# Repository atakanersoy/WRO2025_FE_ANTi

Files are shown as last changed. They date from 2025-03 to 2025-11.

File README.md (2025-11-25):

# 🚀 WRO 2025 Future Engineers – ANTi

<center>
Banner



</center>

---

## 🏆 **TURKISH NATIONAL CHAMPION – READY FOR SINGAPORE FINALS**

Welcome to the GitHub repository of **Team ANTi**, competing in the **World Robot Olympiad™ (WRO®) Future Engineers 2025** category. Our team is made up of Turkish students who have designed a compact, innovative, and autonomous self-driving vehicle to tackle the dynamic challenges of the WRO 2025 competition. Our team name, **ANTi**, reflects our philosophy: like an **ANT**, our robot is exceptionally small yet highly capable, pushing the boundaries of minimalism in design. The "**ANT**i" signifies our competitive spirit, standing "versus the world" in pursuit of engineering excellence.

Our mission was to create the smallest possible robot for the WRO 2025 challenge, leveraging our expertise in electrical, mechanical, and software engineering to test the limits of the 3 m x 3 m game field. After winning the Turkish National Final, we rebuilt, re-tuned, and re-documented every subsystem for the International Final in Singapore on 26–28 Nov 2025.
Current best times on the 3 m x 3 m field:
- **Open Challenge**: 16 seconds (full score)
- **Obstacle Challenge**: 35 seconds (full score)

Complete performance demonstrations available in our [video documentation](video/README.md).

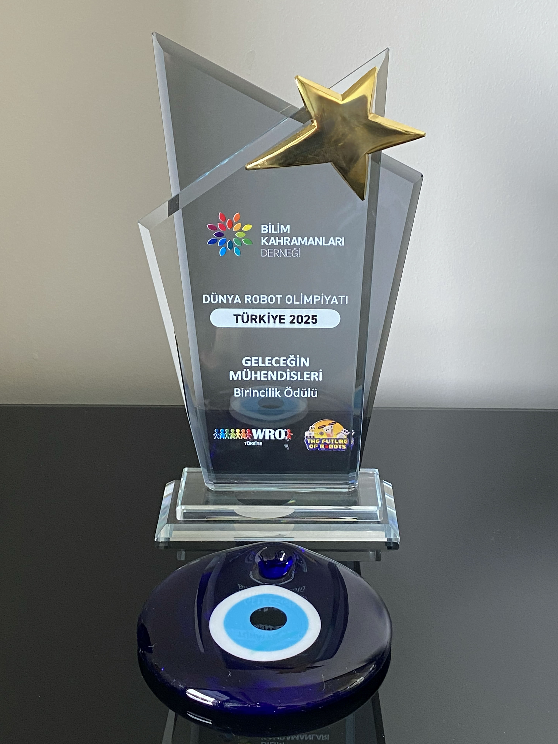
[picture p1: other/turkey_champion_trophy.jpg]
Turkey National Champion Trophy
 

The car keeps its title of **World's Smallest Self Driving Autonomous Vehicle** (about 1/76 scale, **69mm (L) x 53mm (W) x 57mm (H)**) while now carrying more intelligence and sensors than ever before. We challenged ourselves beyond the traditional competition rules by pursuing minimal size alongside advanced engineering functionality to further develop our **engineering knowledge**.

Guided by our vision to ***"never stop developing unless we stop learning,"*** we have created a vehicle that demonstrates how constraints can drive creativity and technical excellence in autonomous systems design. This documentation was last updated on **Sunday, Nov 09 2025, at 09:24 PM +03**

---

## 📚 **Table of Contents**
- [📂 Complete Documentation Structure](#complete-documentation-structure)
- [👥 The Team](#the-team)
- [🎯 Challenge Overview](#challenge-overview)
- [🤖 Our Robot](#our-robot)
- [🔧 Electronic Systems](#electronic-systems)
- [⚙ Mechanical Systems](#mechanical-systems)
- [💻 Software Architecture](#software-architecture)
- [📹 Performance Videos](#performance-videos)
- [🌐 GitHub Utilization & Development](#github-utilization--development)
- [📜 License & Replication](#license--replication)

---

## 📂 **Complete Documentation Structure** 

<div align="center">

## 🔍 **DETAILED TECHNICAL DOCUMENTATION AVAILABLE**

### **Each folder contains comprehensive README documentation with specialized technical content**

| 📁 Folder | 🎯 Technical Content | 📖 Detailed Documentation |
|---|---|---|
| **🧮 MATLAB** | **Vision System Calibration**<br>• LAB colorspace analysis<br>• Threshold optimization<br>• Lighting condition testing | [🔗 Explore MATLAB Documentation](matlab/README.md) |
| **⚙ Models** | **Mechanical Engineering**<br>• 3D CAD designs<br>• Assembly instructions<br>• Gear system calculations | [🔗 Explore 3D Models & Assembly Documentation](models/README.md) |
| **🔌 Schemes** | **Electrical Systems**<br>• Wiring diagrams<br>• Power management<br>• Component schematics & datasheets | [🔗 Explore Schematics & Wiring Documentation](schemes/README.md) |
| **💾 Source Code** | **Software Algorithms**<br>• Navigation logic<br>• Sensor fusion<br>• Control systems | [🔗 Explore Software & Algorithms Documentation](src/README.md) |
| **👥 Team Photos** | **Team Documentation**<br>• Member profiles<br>• Development journey<br>• Competition preparation | [🔗 Explore Team Photos Documentation](t-photos/README.md) |
| **🚗 Vehicle Photos** | **Vehicle Documentation**<br>• Multi-angle views<br>• Component labeling<br>• System integration | [🔗 Explore Vehicle Photos Documentation](v-photos/README.md) |
| **🎥 Videos** | **Performance Validation**<br>• Challenge demonstrations<br>• Engineering tests<br>• System validation | [🔗 Explore Performance Videos Documentation](video/README.md) |
| **📚 Other Resources** | **Technical References**<br>• Component images<br>• Development resources<br>• Additional documentation | [🔗 Explore Additional Resources Documentation](other/README.md) |

</div>

---

## 👥 **The Team** 

Team ANTi includes passionate students from Türkiye, guided by a coach. This is our **first year** competing in the WRO Future Engineers category, and each member brings unique skills to the project, from electronics to computer vision.

<div align="center">
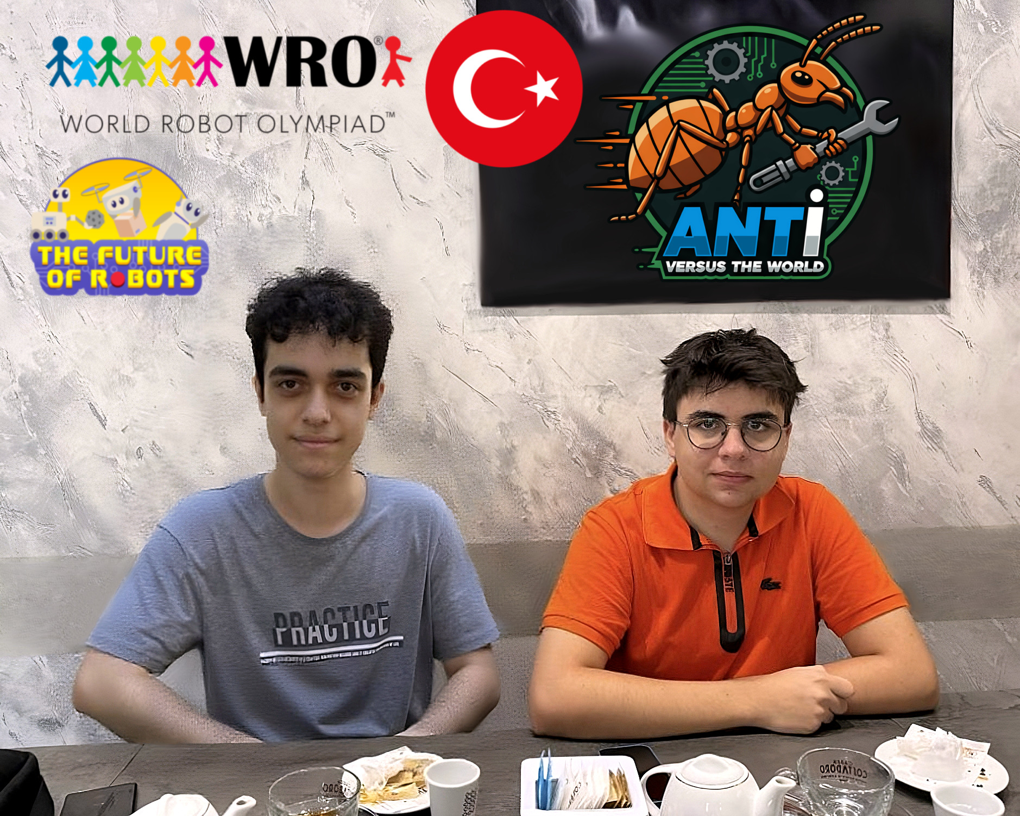
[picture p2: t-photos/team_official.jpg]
Official Team Moment

Team ANTi at Work
</div>

### **Members**
- **Atakan Ersoy** (Team Leader)  
  *Role*: Electronics, Mechanical Design, Software, Strategy Integration  
  *Background*: Sophomore, Electrical and Electronics Engineering, Koç University (2025)  
  *Contact*: [atakan@atakanersoy.com](mailto:atakan@atakanersoy.com), [aersoy24@ku.edu.tr](mailto:aersoy24@ku.edu.tr)  
  *Born*: 2006, Türkiye

- **Ege Özokan**  
  *Role*: Computer Vision Research, Strategy  
  *Background*: Freshman, Computer Engineering, Politecnico di Torino (2025)  
  *Born*: 2006, Türkiye

### **Coach**
- **Ali Aral Eren**  
  *Role*: Team Coach, Connector  
  *Background*: Alumni, Electrical and Electronics Engineering, Koç University (2025)  
  *Born*: 2003, Türkiye  
<br>
<div align="center">
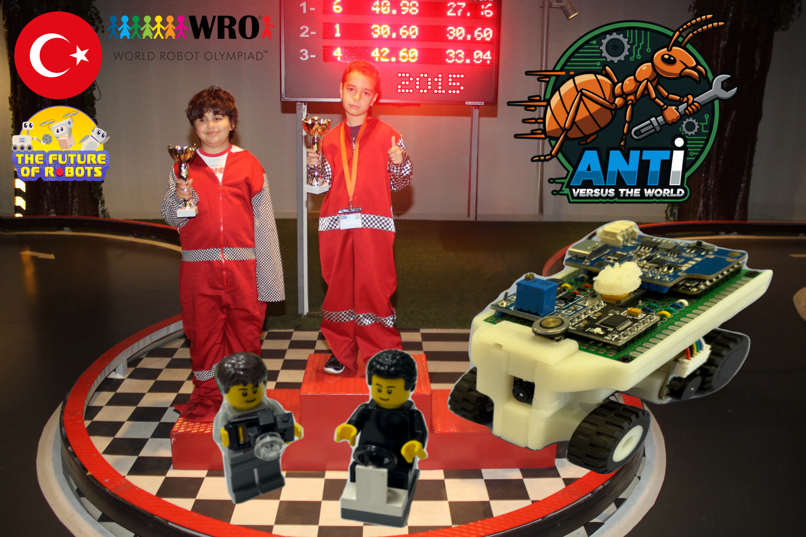
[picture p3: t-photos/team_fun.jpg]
Team ANTi Fun Photo

</div>

> 💡 *Fun Fact*: The fun team photo (`team_fun.jpg`) is our childhood photo from 2015, when we were 9 years old, standing on a go-kart race podium!

### **Team Journey Moments**
Throughout our development process from initial concept to competition readiness, we captured key moments demonstrating our collaborative spirit and technical dedication. These images showcase our brainstorming sessions, technical adjustments, and competition preparation.
<div align="center">
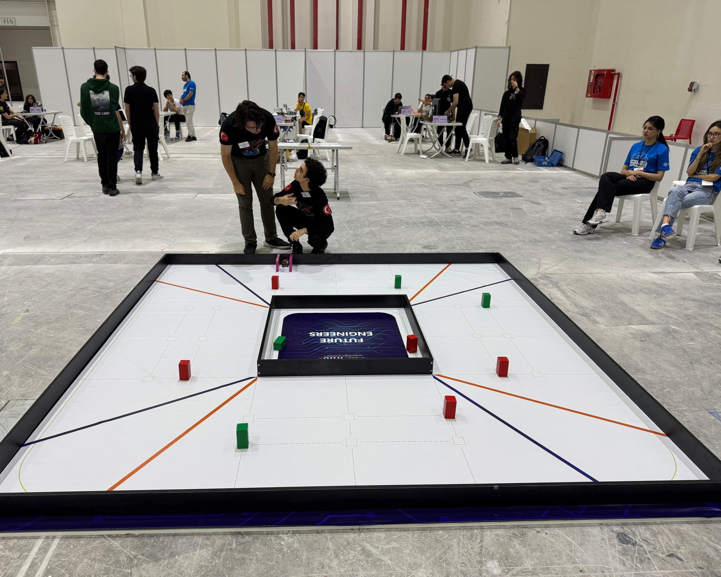
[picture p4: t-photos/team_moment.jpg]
Team Collaboration During National Final

<p><em>Team members collaborating during national final competition - discussing strategy while testing the vehicle on the field and preparing to activate it.</em></p>
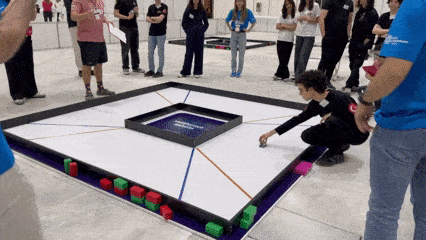
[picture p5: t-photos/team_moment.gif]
Official Competition Start with Team Excitement

<p><em>Dynamic view of official competition start during national final - team member pressing start button with excitement as vehicle begins its run.</em></p>
</div>

---

## 🎯 **Challenge Overview** 

<div align="center">

## 🏁 **WRO 2025 Future Engineers Challenges**

### **Two distinct autonomous navigation challenges testing vehicle intelligence and precision**

</div>

### **🚀 Open Challenge**
<div align="center">

**Objective**: Complete three autonomous laps on dynamically configured tracks

| Aspect | Challenge | Our Solution |
|---|---|---|
| **Track Variability** | Random internal wall placements | Adaptive path planning algorithms |
| **Navigation** | Unknown track layouts each round | Robust wall-following with corner detection |
| **Performance** | Consistent lap times across variations | Optimized PID control and sensor fusion |
| **Precision** | Maintain course in narrow lanes | High-accuracy steering and speed control |

</div>

### **🚧 Obstacle Challenge**
<div align="center">

**Objective**: Navigate three laps with traffic sign compliance and precision parking

| Challenge Element | Requirement | Our Implementation |
|---|---|---|
| **Traffic Signs** | Red → Right bias<br>Green → Left bias | Real-time color detection with LAB colorspace |
| **Obstacle Avoidance** | Dynamic path adjustment | Smooth following at consistent distances |
| **Parking Maneuver** | Parallel parking after lap completion | Multi-stage parking with sensor validation |
| **Navigation** | Shortest path optimization | Efficient routing around obstacle combinations |
</div>

### **📁 Documentation Evaluation Framework**

<div align="center">

## 📊 **WRO 2025 Engineering Documentation Scoring (30 points total)**

| Scoring Area | Maximum Points | Our Documentation Coverage |
|---|---|---|
| **1. Mobility Management** | 4 points | Complete mechanical design, motor selection, steering system, assembly instructions |
| **2. Power & Sense Management** | 4 points | Power systems, sensor integration, wiring diagrams, component specifications |
| **3. Obstacle Management** | 4 points | Navigation algorithms, parking strategies, source code with detailed comments |
| **4. Pictures – Team and Vehicle** | 4 points | Multi-angle vehicle photos, team photos, component labeling |
| **5. Performance Videos** | 4 points | Complete challenge demonstrations with commentary and analysis |
| **6. GitHub Utilization** | 4 points | Version control, structured documentation, regular commits |
| **7. Engineering Factor** | 4 points | Custom design and manufacturing throughout the vehicle |
| **8. Overall Judge Impression** | 2 points | Clear communication enabling easy replication |
| **Total Documentation Score** | **30 points** | **(≈25% of total competition score)** |
</div>

### **Key Evaluation Areas**
- **Performance and adaptability** in randomized track conditions
- **Precision in maneuvers**, especially parallel parking execution  
- **Comprehensive public engineering documentation** on GitHub with complete transparency
- **Custom design innovation** and manufacturing process documentation
- **Professional presentation** enabling effortless replication by other teams

**Scoring Philosophy**: Documentation is evaluated based on completeness, structure, and ease of replication - not comparison between teams. Each scoring area uses a 0-4 point scale where "Exceeds Expectations" requires not only enabling exact duplication but also providing improvement suggestions.

### **🎓 Educational Objectives**
- **Advanced Computer Vision**: Real-world implementation of color space theory
- **Sensor Fusion**: Integrating multiple data sources for robust navigation
- **Control Systems**: Precision steering and speed control algorithms
- **Engineering Documentation**: Professional technical communication
- **Problem Solving**: Systematic approach to technical challenges

---

## 🤖 **Our Robot** 

<div align="center">
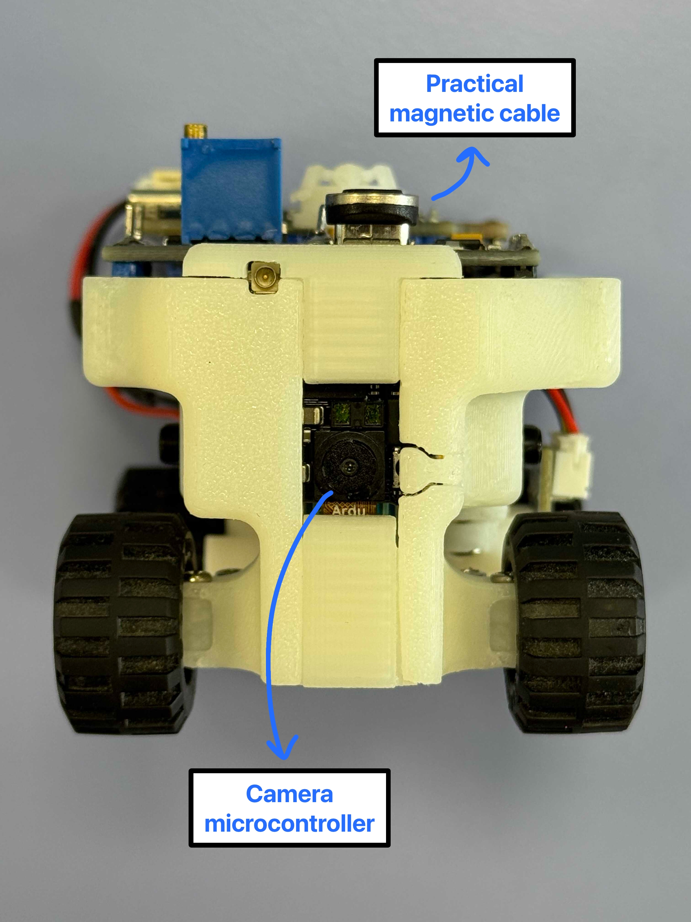
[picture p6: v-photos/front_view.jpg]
ANTi Autonomous Vehicle

</div>

Our platform represents a breakthrough in compact autonomous vehicle design, achieving unprecedented miniaturization without compromising capability. The complete system integrates custom mechanical design with sophisticated electronic systems and advanced software algorithms.

**Core Processing Architecture**:
- **Primary Vision Processor**: STM32H747 dual-core microcontroller dedicated to real-time image processing
- **Secondary Sensor Processor**: nRF52832 microcontroller handling multi-sensor data fusion
- **Distributed Processing**: Optimized task allocation between vision and control subsystems

**Perception System**:
- **Front-Facing Detection**: VL53L1X Time-of-Flight sensor for general obstacle awareness
- **Side-Mounted Precision Sensors**: Dual VL53L3CX ToF sensors with custom optics for parking detection
- **Visual Navigation**: GC2145 2MP camera with optimized field of view for track following

**Propulsion and Control**:
- **Drive System**: 1500 RPM N20 motor with integrated encoder feedback
- **Steering Mechanism**: Custom Ackermann geometry with submicro servo actuation
- **Power Management**: Integrated LiPo system with comprehensive power distribution

Complete vehicle documentation with detailed component identification available in [vehicle photos](v-photos/README.md).

<div align="center">
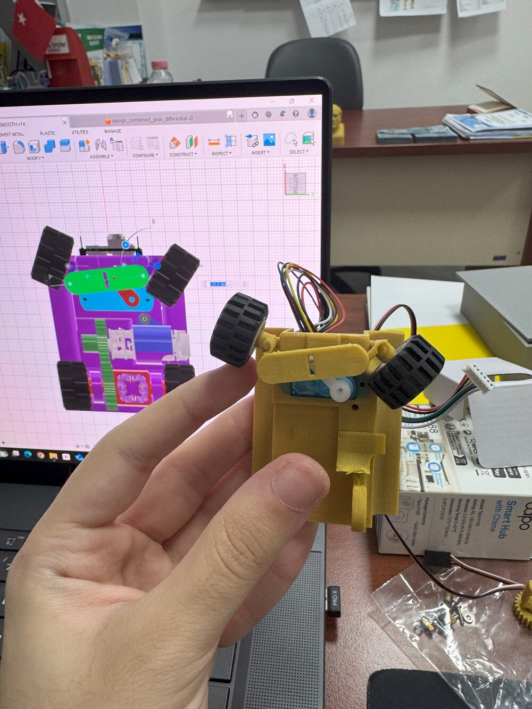
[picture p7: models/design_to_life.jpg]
Digital to Physical Realization

</div>

### Potential Future Improvements (Overall Vehicle)
- Reduce size even further to ≈ 60 × 45 × 50 mm by switching to smaller LiPo (3.7 V), a coreless motor + micro gearbox and smaller mechanic differential style.
- Implement four-wheel steering or active rear-axle 4 wheel drive to control for tighter turning radius on narrow lanes.
- Add a very small extra second camera facing backwards for reverse parking or emergency obstacle detection.

---

## 🔧 **Electronic Systems** 

Our electronic architecture emphasizes modularity, reliability, and hands-on engineering through custom manufacturing approaches.

### **Component Integration Strategy**

<div align="center">

| Component | Image | Quantity | Function | Key Specifications |
|---|---|---|---|---|
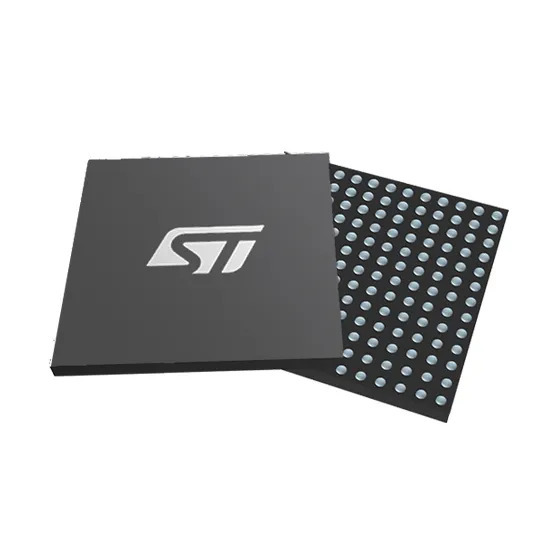
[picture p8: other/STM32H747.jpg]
| **STM32H747** |  | 1 | Vision Processing | Dual-core Cortex-M7/M4, Camera Interface |
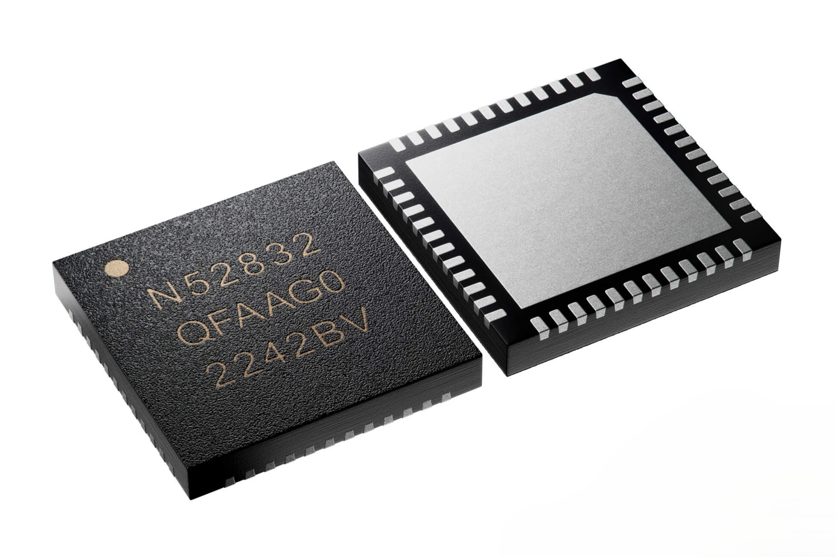
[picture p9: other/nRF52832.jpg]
| **nRF52832** |  | 1 | Sensor Fusion | Multi-protocol wireless capable MCU |
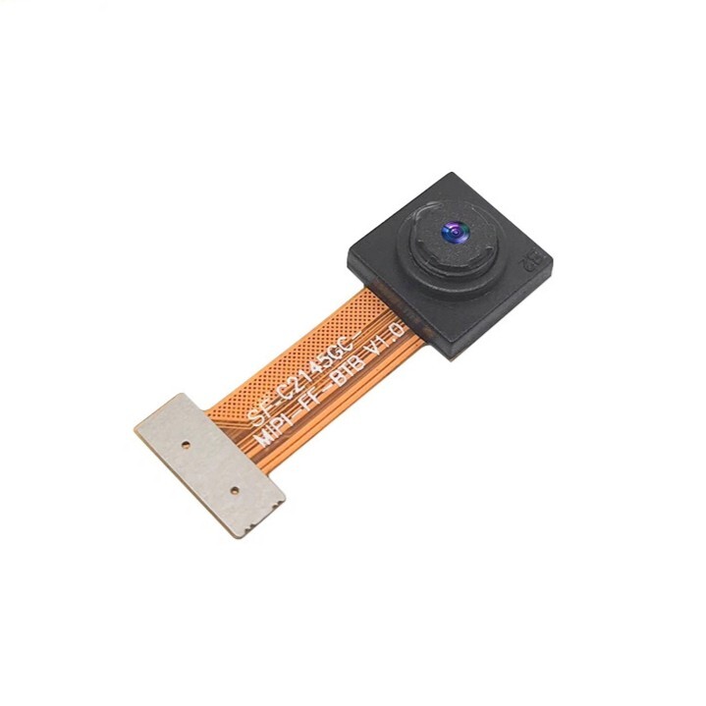
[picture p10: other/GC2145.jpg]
| **GC2145 Camera** |  | 1 | Visual Navigation | 2MP resolution, 80° FOV, DCMI interface |
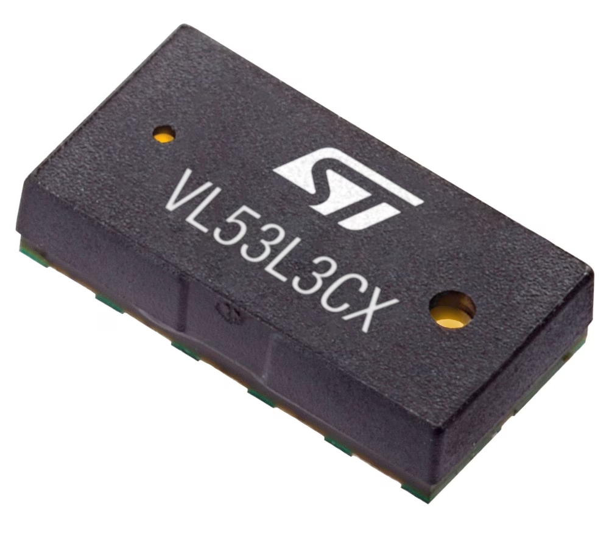
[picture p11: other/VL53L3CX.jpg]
| **VL53L3CX ToF** |  | 2 | Side Detection | 700cm range, window lens optics |
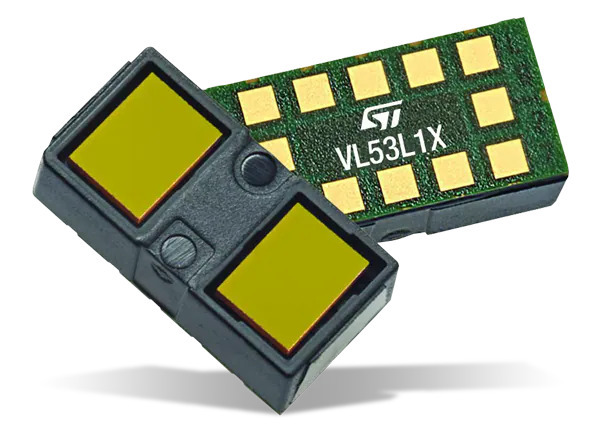
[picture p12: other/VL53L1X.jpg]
| **VL53L1X ToF** |  | 1 | Front Detection | 400cm range, programmable FoV |
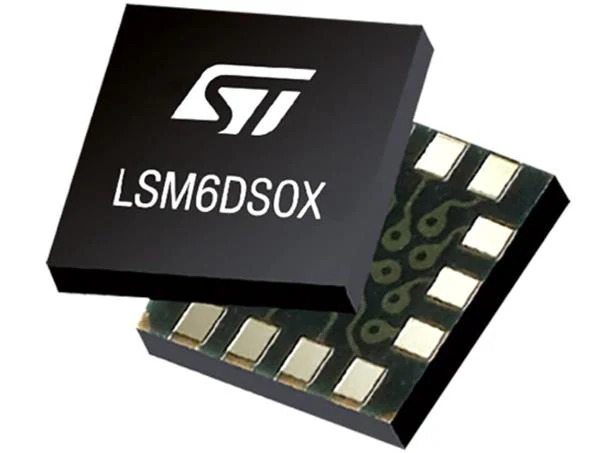
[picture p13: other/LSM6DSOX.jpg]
| **LSM6DSOX IMU** |  | 1 | Motion Tracking | 6-axis inertial measurement |
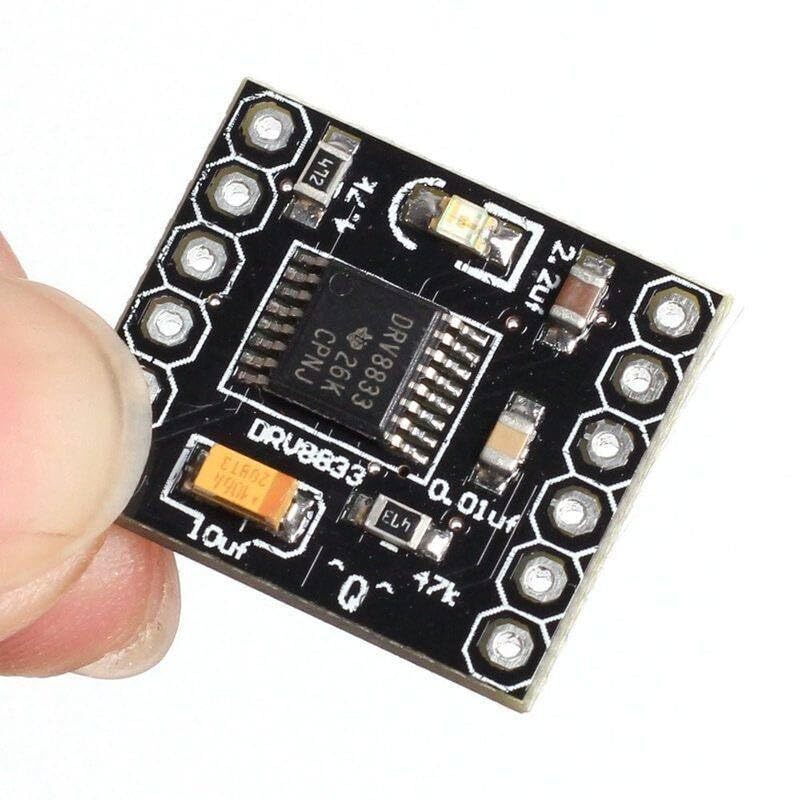
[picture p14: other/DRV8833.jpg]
| **DRV8833 Driver** |  | 1 | Motor Control | Dual H-bridge, PWM control |
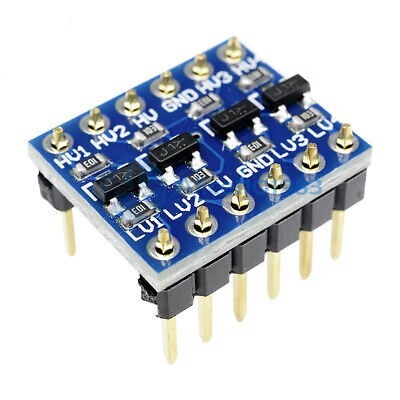
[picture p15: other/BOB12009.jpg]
| **BOB-12009** |  | 1 | Level Shifting | Bidirectional 3.3V-5V conversion |
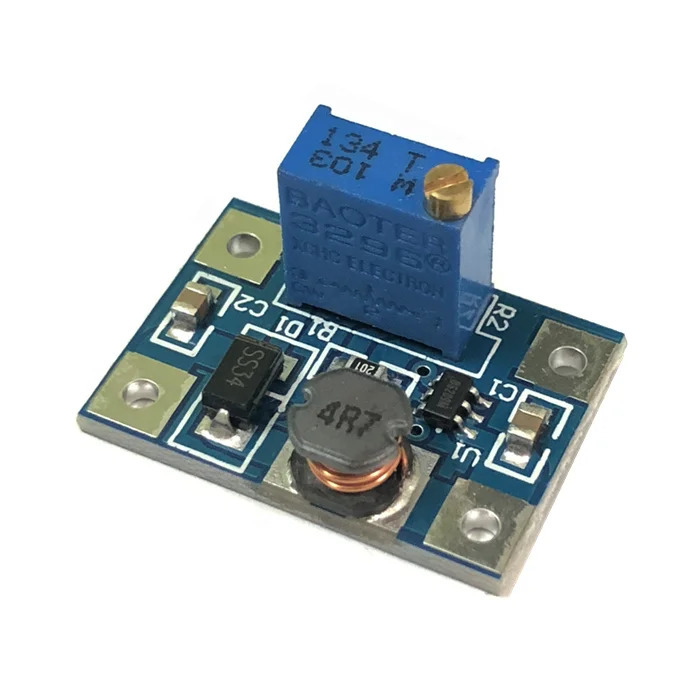
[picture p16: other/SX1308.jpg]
| **SX1308 Booster** |  | 1 | Power Regulation | 2A step-up voltage conversion |
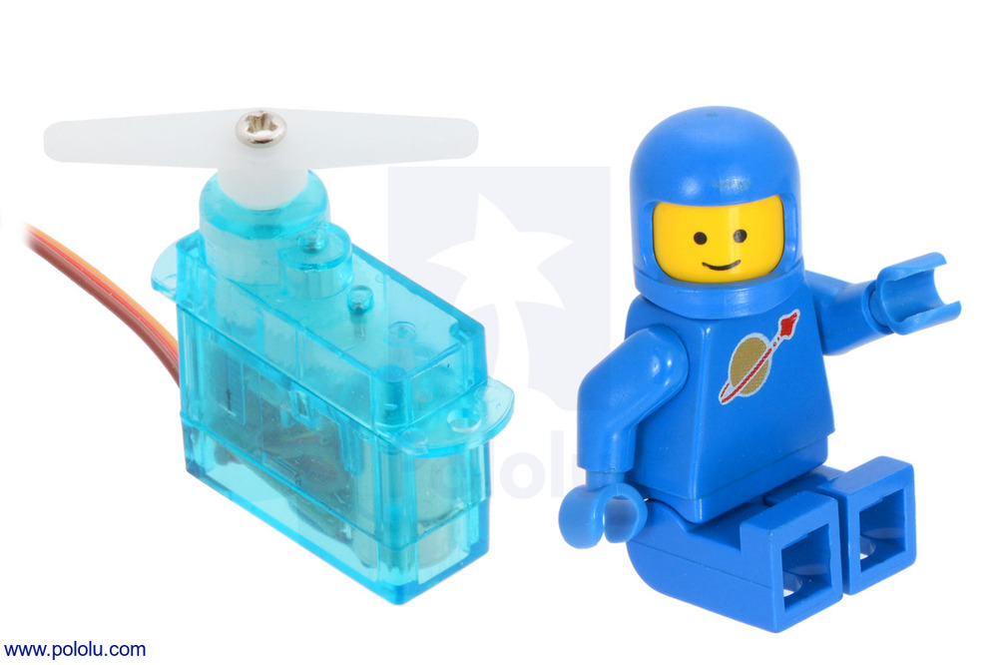
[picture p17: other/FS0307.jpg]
| **Feetech FS0307** |  | 1 | Steering Actuation | Submicro form factor, precision control |
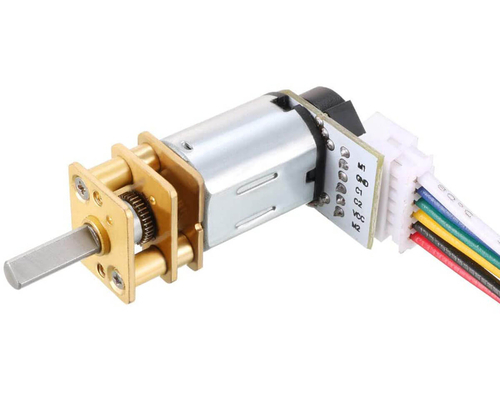
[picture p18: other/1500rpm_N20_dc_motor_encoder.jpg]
| **1500 RPM N20** |  | 1 | Propulsion | Brushed DC with Hall effect encoder |
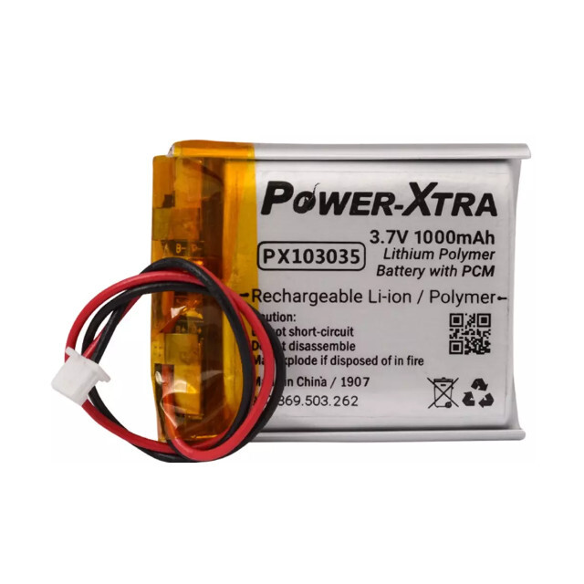
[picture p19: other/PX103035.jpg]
| **PX103035 Battery** |  | 1 | Power Source | 1000mAh LiPo with protection circuit |
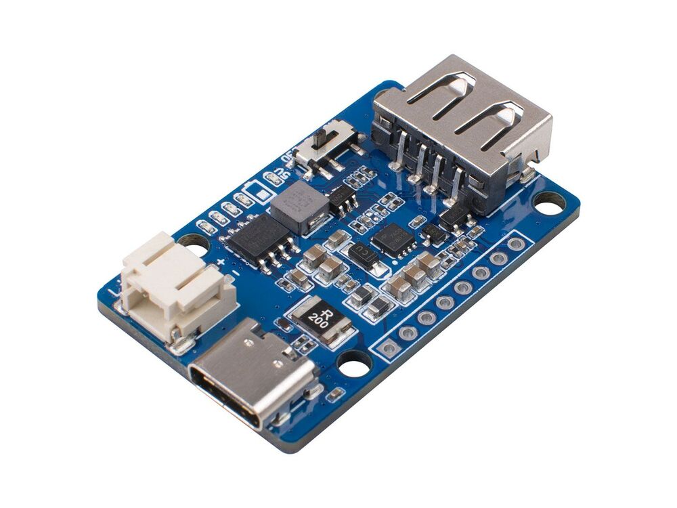
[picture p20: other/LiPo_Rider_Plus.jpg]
| **LiPo Rider Plus** |  | 1 | Power Management | USB-C charging, multi-rail output |
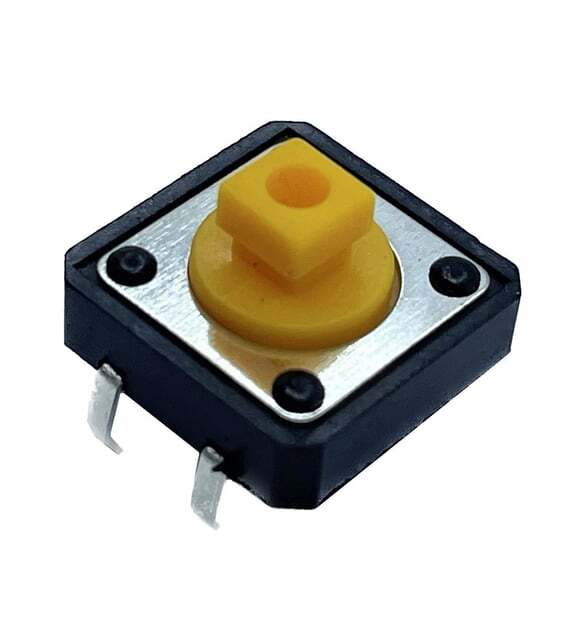
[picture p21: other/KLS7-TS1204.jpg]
| **KLS7-TS1204** |  | 1 | User Interface | Tactile switch for system control |
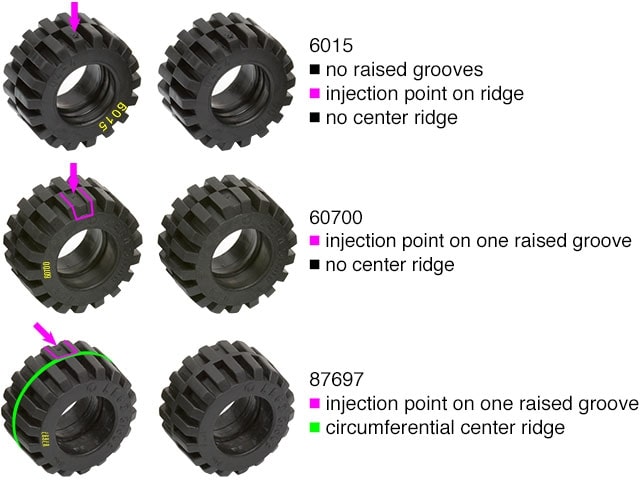
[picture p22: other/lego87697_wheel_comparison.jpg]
| **LEGO 87697** |  | 4 | Traction System | 21mm diameter, optimized tread pattern |

</div>

**Component Selection Philosophy**: We prioritize widely available, well-documented components to ensure reproducibility. All parts can be sourced through standard electronics distributors using the provided specifications and images.

### **Professional Wiring Implementation**

<div align="center">
  <a href="schemes/wiring_diagram.jpg" target="_blank"> 
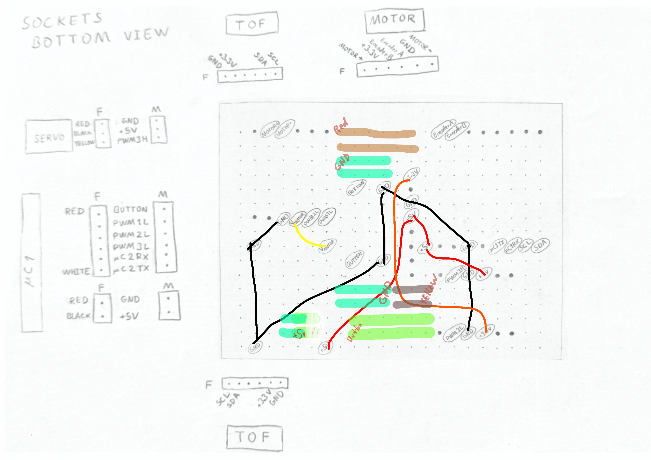
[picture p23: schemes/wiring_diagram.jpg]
Professional Wiring Diagram
    
  </a>
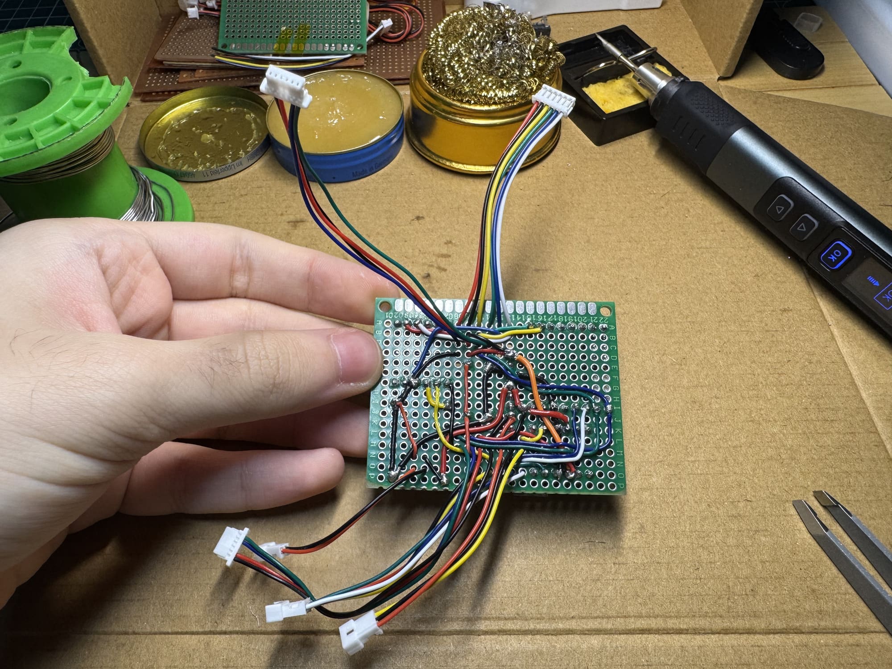
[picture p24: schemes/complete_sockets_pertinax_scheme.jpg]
  
</div>
<p align="center">
  <em>1) Complete hand-drawn and digitally traced professional wiring schematic showing all electrical connections (<a href="schemes/wiring_diagram.jpg" target="_blank">view full resolution</a>) • 2) Physical implementation demonstrating socket-based construction of the schematic</em>
</p>

### **Individual Component Schematics**

<div align="center">

| Component Schematic | Description | Full Documentation |
|---|---|---|
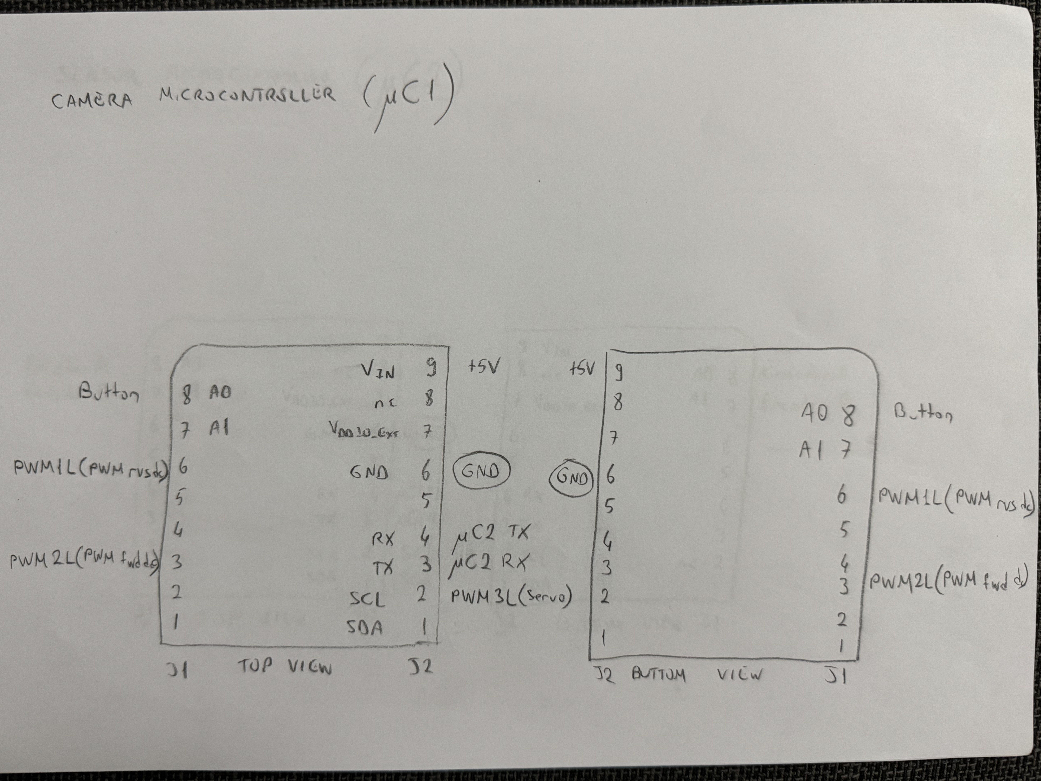
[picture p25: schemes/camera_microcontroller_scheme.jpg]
|  | **STM32H747 Camera Controller**<br>Camera interface and peripheral connections | [View Details](schemes/README.md#microcontroller-systems) |
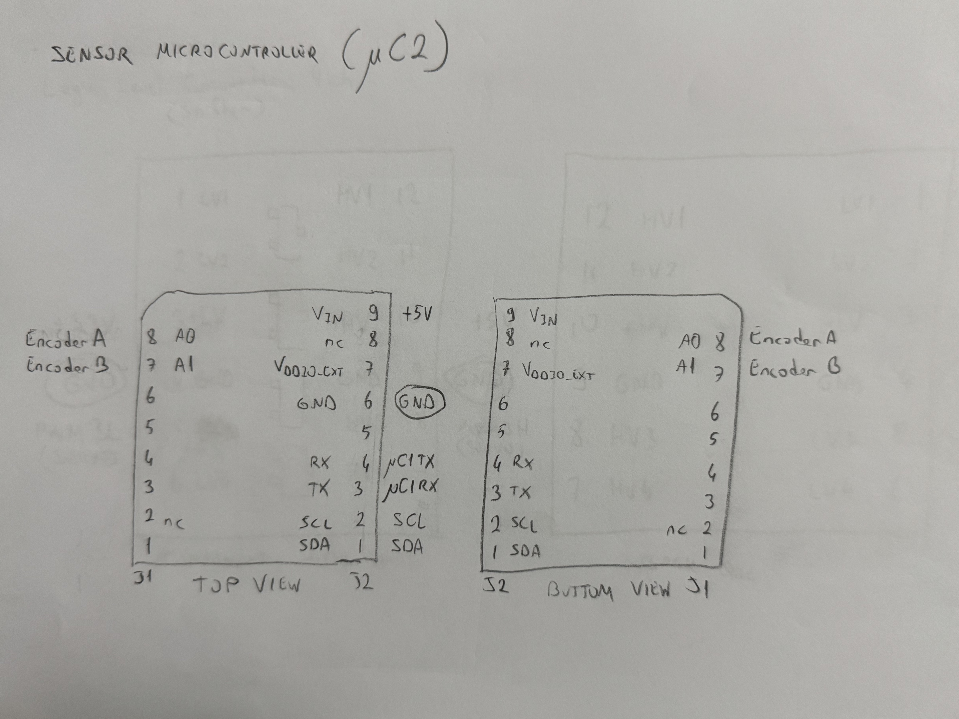
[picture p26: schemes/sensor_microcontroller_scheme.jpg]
|  | **nRF52832 Sensor Processor**<br>ToF sensors and sensor fusion integration | [View Details](schemes/README.md#microcontroller-systems) |
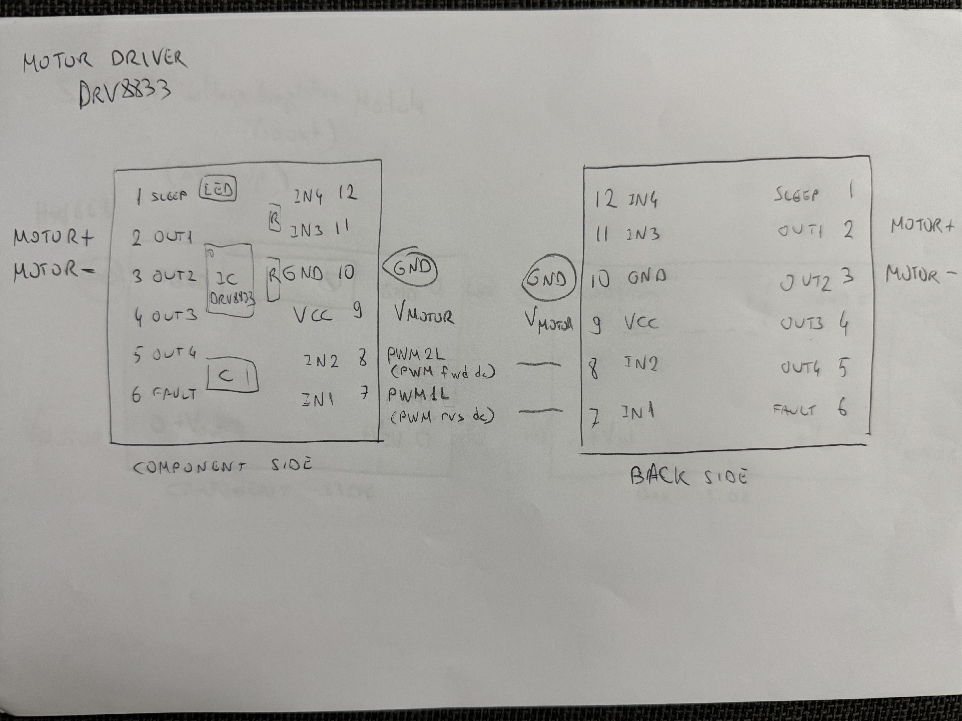
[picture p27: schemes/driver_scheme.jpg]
|  | **DRV8833 Motor Driver**<br>Motor control that uses SX1308 voltage boosting | [View Details](schemes/README.md#motor-control-systems) |
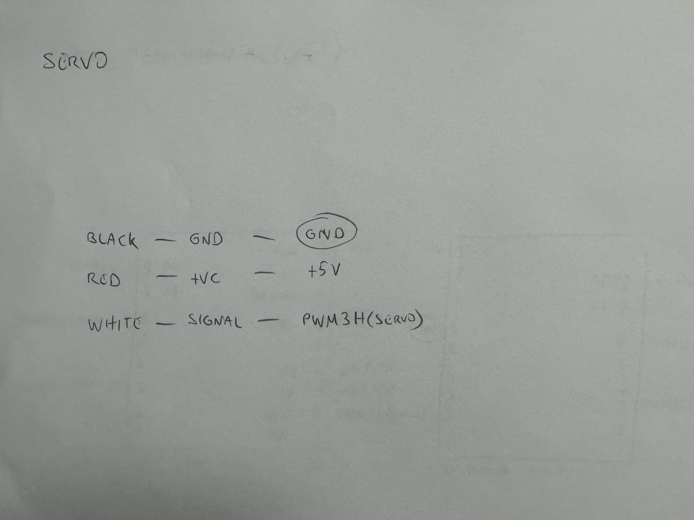
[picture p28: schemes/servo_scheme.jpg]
|  | **FS0307 Servo Control**<br>Steering mechanism that uses BOB-12009 level conversion | [View Details](schemes/README.md#motor-control-systems) |
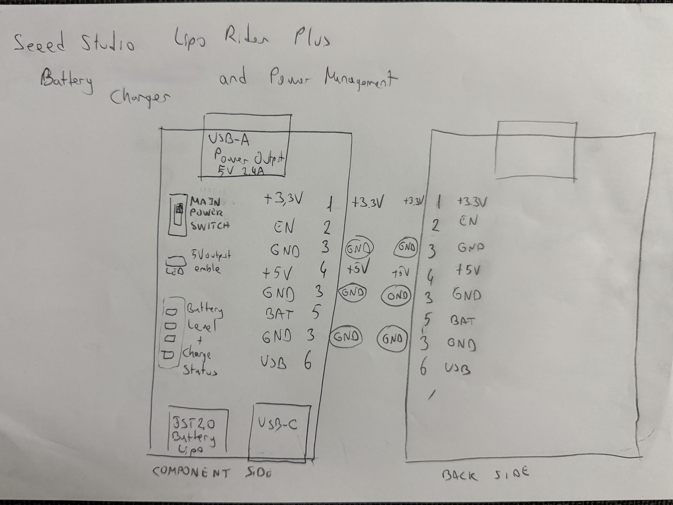
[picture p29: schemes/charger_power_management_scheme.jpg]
|  | **Power Management System**<br>LiPo charging and distribution | [View Details](schemes/README.md#power-management-components) |
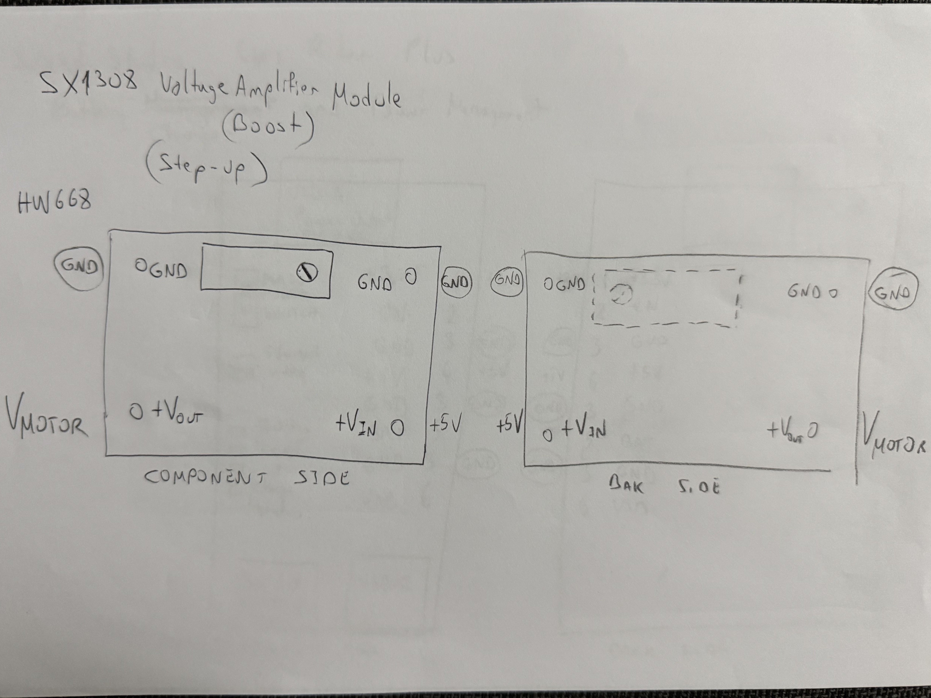
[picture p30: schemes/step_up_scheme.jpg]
|  | **SX1308 Voltage Booster**<br>Motor power regulation | [View Details](schemes/README.md#power-management-components) |
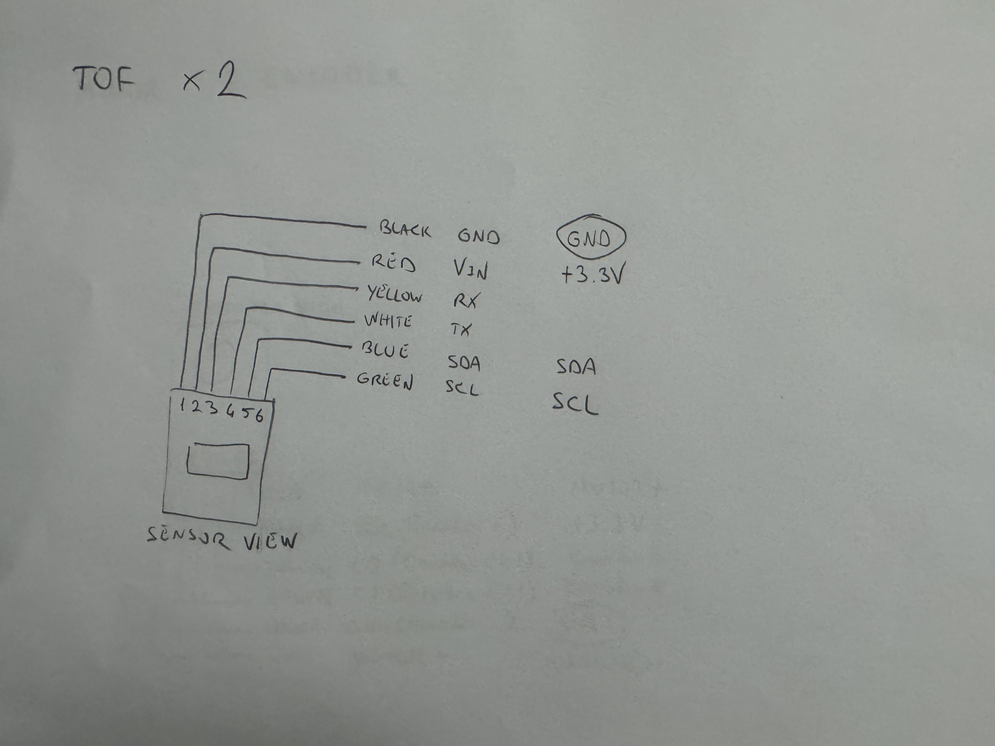
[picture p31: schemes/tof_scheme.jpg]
|  | **ToF Sensor Network**<br>Distance measurement system | [View Details](schemes/README.md#time-of-flight-sensor-system) |
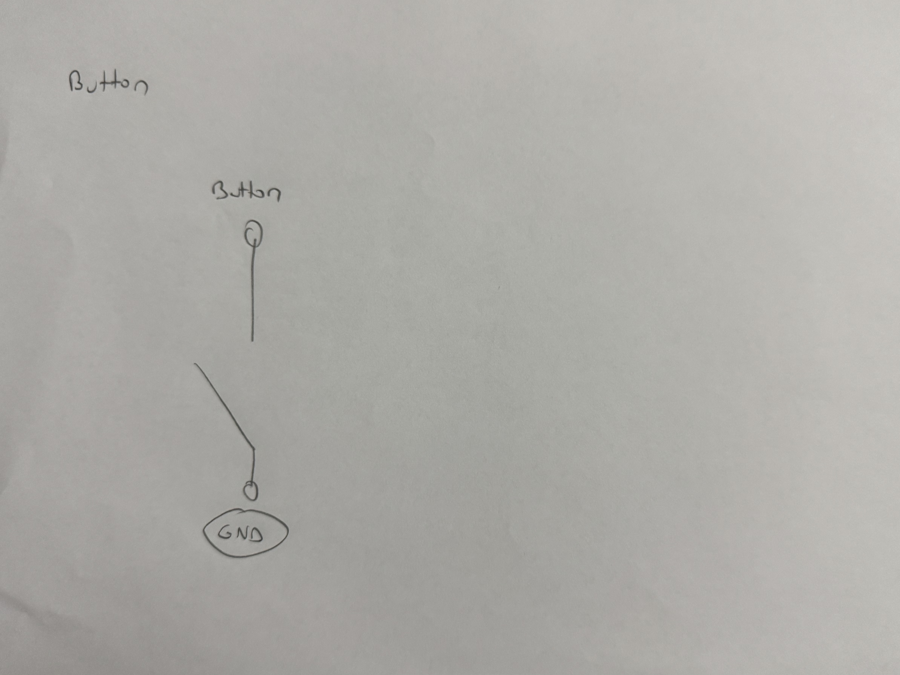
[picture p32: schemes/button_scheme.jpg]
|  | **User Interface**<br>Start button and control interface | [View Details](schemes/README.md#-interface--control-systems) |
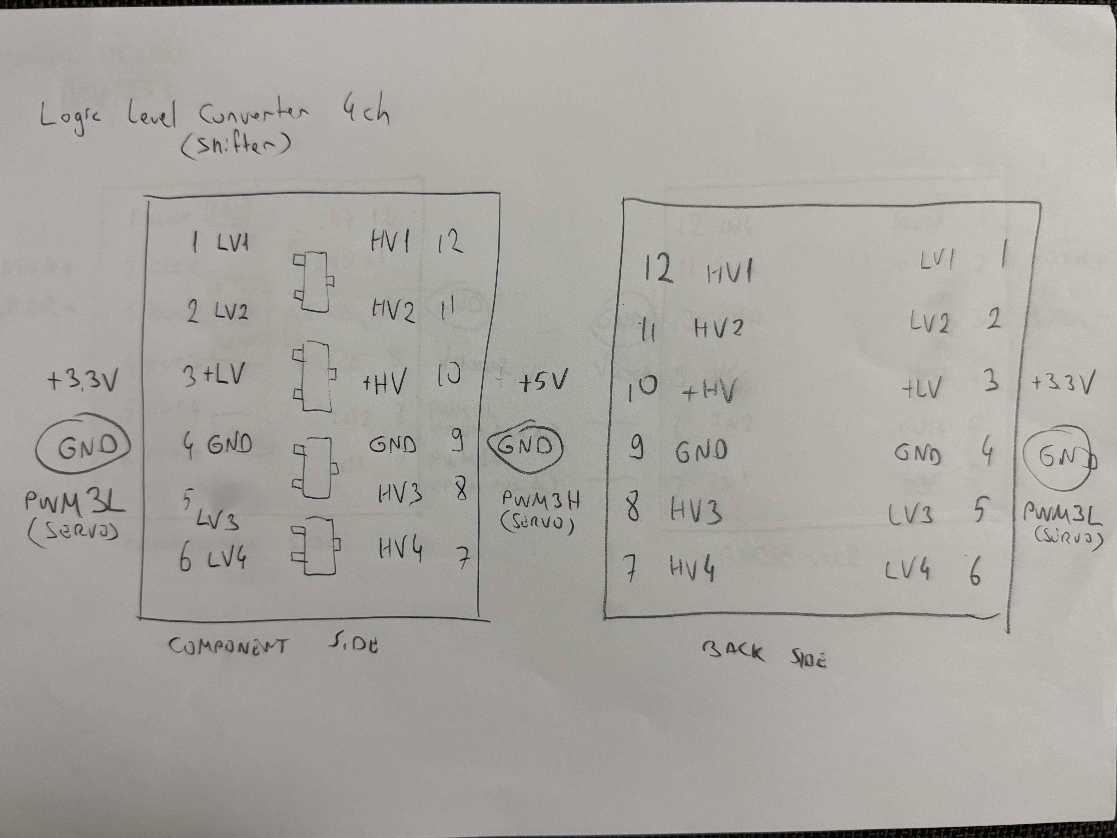
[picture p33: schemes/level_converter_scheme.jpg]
|  | **BOB-12009 Logic Level Converter**<br>3.3V-5V signal conversion for servo | [View Details](schemes/README.md#-interface--control-systems) |
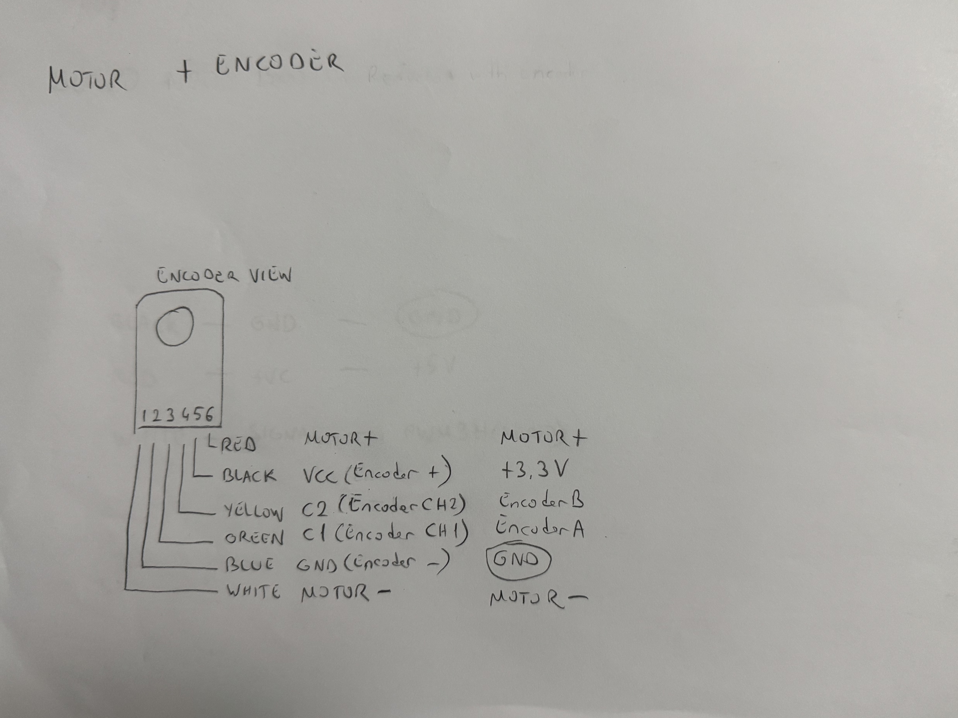
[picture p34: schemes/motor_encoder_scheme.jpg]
|  | **N20 DC Motor + Encoder**<br>Brushed DC motor with Hall effect encoder | [View Details](schemes/README.md#motor-control-systems) |

</div>

### **Power Management Innovation**

During system integration, we identified a critical design limitation in our chosen power management IC. The LiPo Rider Plus's switch only controlled the 5V output rail, leaving the 3.3V regulator permanently active and creating potential battery drain.

**Engineering Solution**:
- **Root Cause Analysis**: 3.3V LDO connected directly to battery input, bypassing power switch
- **Component Modification**: Desoldered USB-A port and reconfigured LDO input routing
- **Implementation**: Redirected LDO input to switched 5V rail using original mounting points
- **Validation**: Complete power control achieved with zero standby current draw

<div align="center">
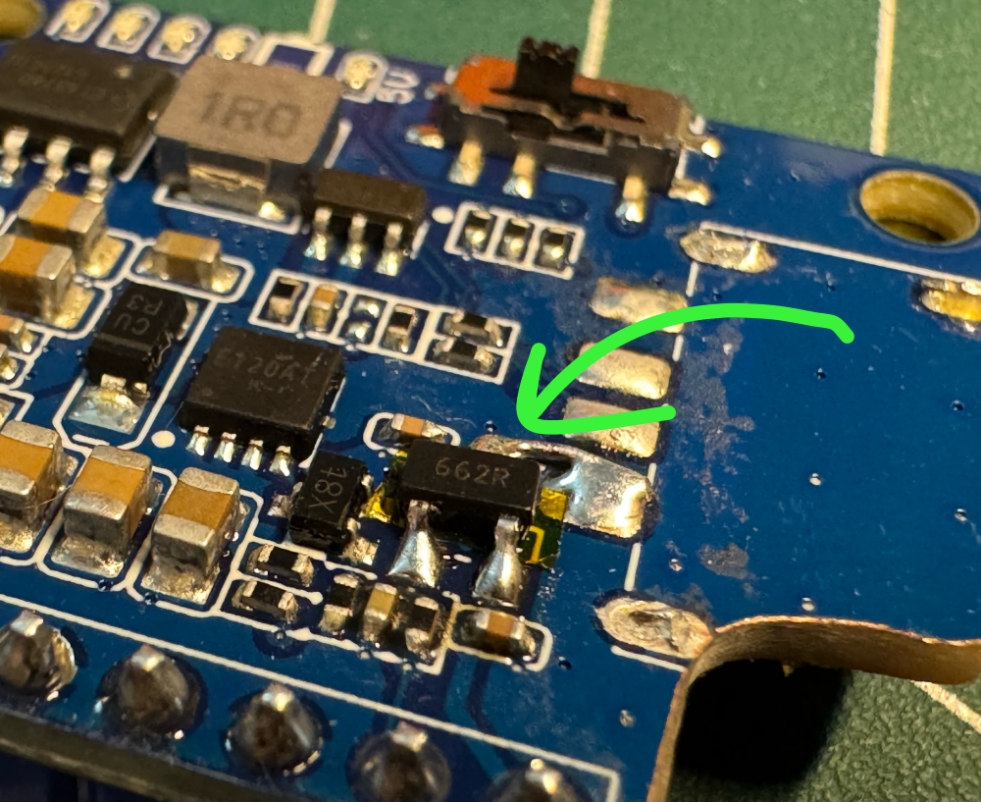
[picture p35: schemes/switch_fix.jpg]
Power Management Modification

<p><em>Hardware modification enabling complete power rail control through single switch</em></p>
</div>

### **Signal Integrity Systems**

The **BOB-12009 logic level converter** ensures reliable communication between our 3.3V microcontrollers and 5V servo system. This implementation prevents signal degradation and ensures precise servo positioning under all operating conditions.

### **Thermal Performance Validation**

Comprehensive thermal analysis confirmed optimal operating temperatures across all critical subsystems:

<div align="center">
<table>
<tr>
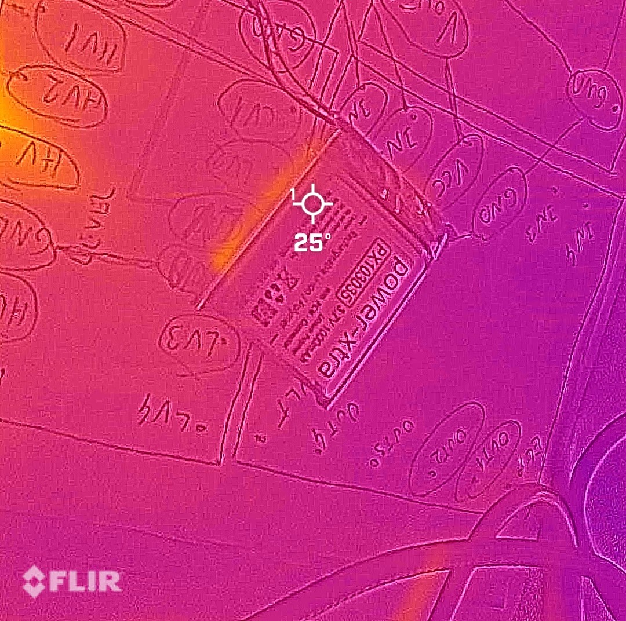
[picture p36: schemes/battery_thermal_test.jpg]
<td align="center"><br><strong>Power Cell: 25°C</strong></td>
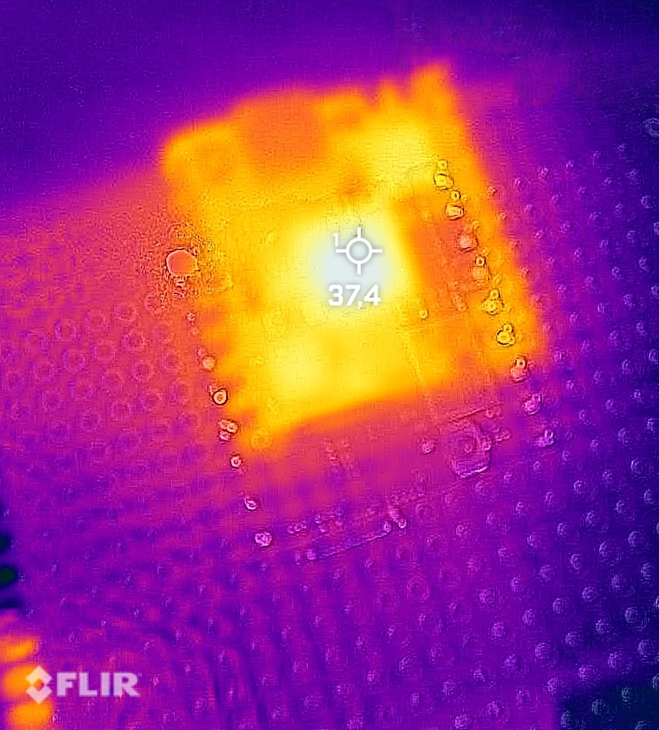
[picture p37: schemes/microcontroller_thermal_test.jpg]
<td align="center"><br><strong>Processor: 37°C</strong></td>
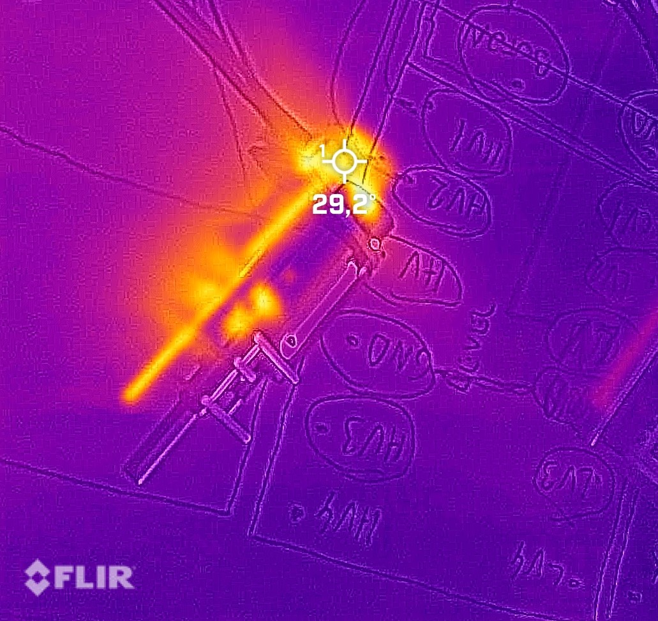
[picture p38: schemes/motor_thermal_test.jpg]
<td align="center"><br><strong>Drive Unit: 29°C</strong></td>
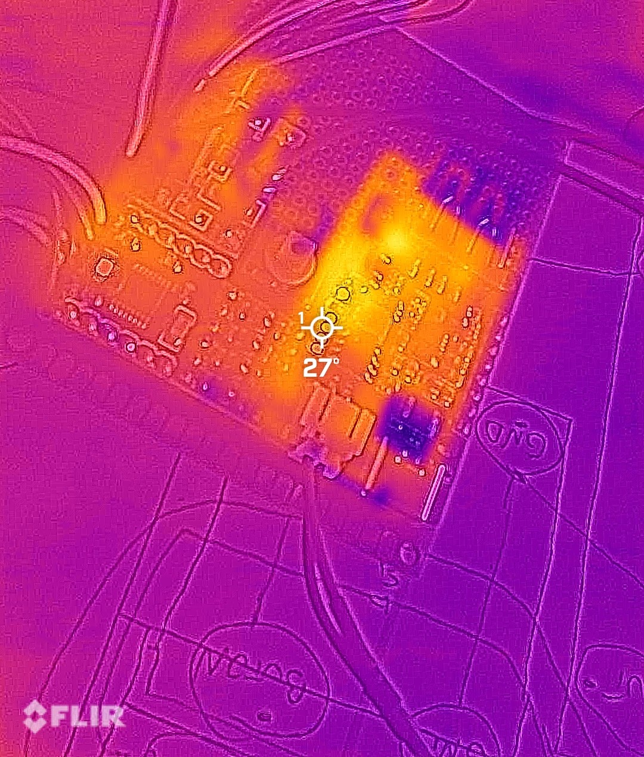
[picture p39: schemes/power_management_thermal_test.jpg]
<td align="center"><br><strong>Power IC: 27°C</strong></td>
</tr>
</table>
</div>

### **Custom Manufacturing Approach**

Facing extreme space constraints, we developed an innovative double-layer pertinax board solution inspired by multi-layer PCB technology. This approach allowed complete in-house manufacturing while providing invaluable hands-on experience in circuit design and fabrication.

<div align="center">
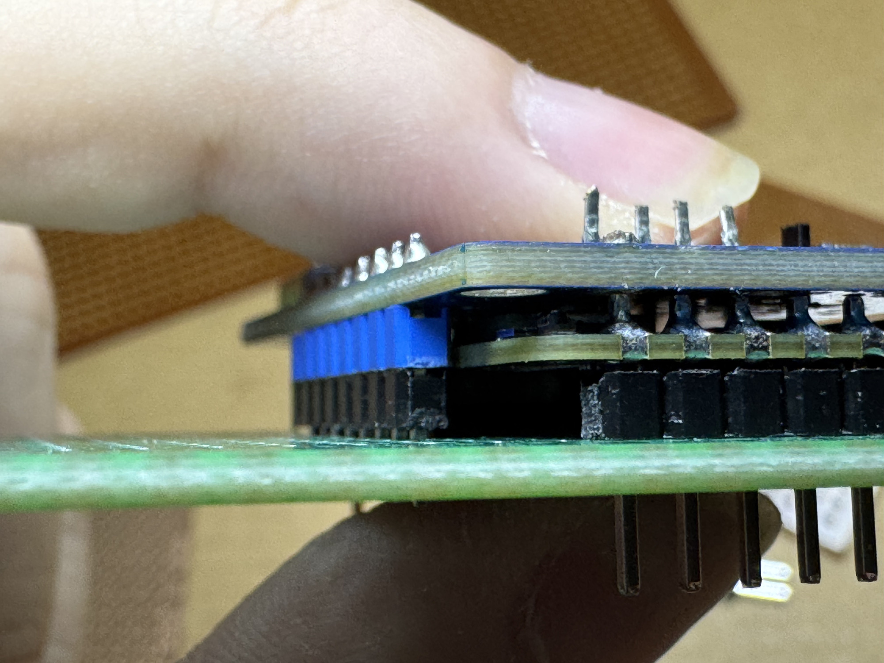
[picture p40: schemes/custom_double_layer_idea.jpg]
Multi-layer Board Design

<p><em>Custom double-layer pertinax implementation with component stacking</em></p>
</div>

**Manufacturing Benefits**:
- **Rapid Iteration**: Immediate design modifications without external fabrication delays
- **Cost Efficiency**: Significant reduction compared to professional PCB services
- **Educational Value**: Comprehensive understanding of circuit construction and troubleshooting
- **Maintenance Advantage**: Socket-based design enables component-level serviceability

**Insulation Strategy**: Kapton tape application between layers prevents electrical contact while maintaining mechanical stability.

### **Sensor Integration Challenges**

Our minimal vertical profile created unique challenges for Time-of-Flight sensor implementation. The proximity to ground plane caused premature ground intersection in the sensors' field of view, limiting effective detection range.

**Optical Solution**:
- **Angular Adjustment**: Upward sensor tilt to delay ground intersection
- **Optical Modification**: Custom window lenses to narrow field of view
- **Performance Improvement**: Extended usable detection range from ~150cm to ~300cm

### **Development Convenience Features**

Implementation of magnetic USB connectors for programming interfaces significantly improved development workflow efficiency, allowing rapid code iterations without physical connector wear.

<div align="center">
Development Interface Access
<p><em>Easy-access programming interface with magnetic connection system</em></p>
</div>

### **Performance Specifications**

- **Maximum Theoretical Speed**: 1.72 m/s (calculated from motor RPM and drive train ratios)
- **Operational Speed**: 1.4 m/s (PWM controlled for stability optimization)
- **Battery Endurance**: 4-5 hours typical operation
- **Charge Duration**: ~45 minutes via USB-C fast charging
- **Power Consumption**: 0.8W minimum, 200-250mA typical operational current

### Powertrain – Potential Improvements
- Switch to higher RPM coreless motor + greater 50:1 Micro Metal Gearbox → theoretical top speed > 2.3 m/s while keeping the same design.
- Replace the 26:25 external gear with an internal planetary stage inside the N20 motor can → saves 4 mm length with direct mounting of the motor to the rear axle.
- Active cooling (micro 10 mm fan, 0.8 g) → could improve the overall airflow in the system, allowing for faster operation and even higher stability.

---

## ⚙ **Mechanical Systems** 

Our mechanical design philosophy centers on achieving maximum capability within minimal dimensions through innovative engineering and precision manufacturing.

### **Core Mechanical Specifications**
- **Overall Dimensions**: 69mm (L) × 53mm (W) × 57mm (H)
- **Total Mass**: Approximately 130 grams
- **Structural Material**: 3D-printed ABS for optimal strength-to-weight ratio
- **Drive Configuration**: Rear-wheel drive with custom differential
- **Steering System**: True Ackermann geometry with precision linkage

### **Design Integration Approach**

<div align="center">
Digital Design Model
Physical Implementation
</div>
<p align="center">
  <em>Digital design precision translated to physical implementation through advanced manufacturing techniques</em>
</p>

### **Steering Geometry Implementation**

Our custom Ackermann steering system ensures each wheel maintains optimal alignment during turns, minimizing tire scrub and maximizing maneuverability.

<div align="center">
Steering Mechanism Animation
Steering Geometry Analysis
</div>
<p align="center">
  <em>Dynamic steering simulation and geometric analysis ensuring optimal turning performance</em>
</p>

**Steering System Evolution**:
- **Initial Concept**: Integrated print-in-place mechanism for rapid prototyping
- **Performance Refinement**: Multi-component assembly for long-term precision
- **Final Implementation**: Four M2 fasteners with locking nuts for permanent alignment
- **Wheel Articulation**: -50° to +32° range optimized for competition track dimensions

### Mechanical – Potential Improvements
- True Ackermann geometry with adjustable tie-rod lengths for further adjustability.
- Ball bearings on all four kingpins and differential gears → theoretical 7–9 % less rolling resistance in CAD tests.
- Possible uspension system using micro torsion bars could improve stability if the track includes ground obstacles in the future when crossing the 3 mm track.

### **Power Transmission System**

The custom 4-gear differential ensures smooth torque distribution during turning maneuvers, preventing wheel slip and maintaining traction.

<div align="center">
<table align="center">
<tr>
<td align="center">
Differential Function Test
</td>
<td align="center">
Differential Assembly View 1<br>
Differential Assembly View 2
</td>
</tr>
</table>
</div>
<p align="center">
  <em>Physical validation of differential operation and comprehensive CAD documentation</em>
</p>

**Gear System Architecture**:
- **Speed Reduction**: 26:25 ratio through custom spur gear design
- **Torque Distribution**: Four 12-tooth bevel gears enabling independent wheel rotation
- **Manufacturing Precision**: 100% infill for maximum durability under load
- **Efficiency Optimization**: Precisely calculated tooth profiles for minimal power loss

### **Manufacturing File Repository**

*All components provided in 3MF format for maximum compatibility across different 3D printing platforms and slicing software*

<div align="center">

| Component | File Reference | Quantity | Visual Reference | Functional Description |
|---|---|---|---|---|
| **Main Chassis** | [`design_base.3mf`](models/design_base.3mf) | 1 |  | Primary structural element with integrated mounting features |
| **4-Gear Differential** | [`design_4_gear_mini_differential.3mf`](models/design_4_gear_mini_differential.3mf) | 1 |  | Complete differential assembly with integrated gear mounting |
| **Front Rim Assembly** | [`design_front_rim_bearing.3mf`](models/design_front_rim_bearing.3mf) | 2 |  | Steering wheels with integrated bearing seats |
| **Steering Arm** | [`design_steering_arm.3mf`](models/design_steering_arm.3mf) | 2 |  | Ackermann steering linkage arms (left/right pair) |
| **Steering Linkage** | [`design_steering_linkage.3mf`](models/design_steering_linkage.3mf) | 1 |  | Central steering connection mechanism |
| **25T Spur Gear** | [`design_spur_25_gear.3mf`](models/design_spur_25_gear.3mf) | 1 |  | 25-tooth torque transmission gear |
| **26T Spur Gear** | [`design_spur_26_gear.3mf`](models/design_spur_26_gear.3mf) | 1 |  | 26-tooth motor interface gear |
| **12T Bevel Gear** | [`design_bevel_12_gear.3mf`](models/design_bevel_12_gear.3mf) | 4 |  | Differential bevel gears (set of 4 required) |
| **Motor Enclosure** | [`design_motor_lid.3mf`](models/design_motor_lid.3mf) | 1 |  | N20 motor protective housing |
| **Long Rear Rim** | [`design_back_rim_long.3mf`](models/design_back_rim_long.3mf) | 1 |  | Extended right-side drive wheel |
| **Short Rear Rim** | [`design_back_rim_short.3mf`](models/design_back_rim_short.3mf) | 1 |  | Compact left-side drive wheel |
| **Front Upper Cover** | [`design_front_top_cover.3mf`](models/design_front_top_cover.3mf) | 1 |  | Electronics protection shield |
| **Front Lower Cover** | [`design_front_bottom_cover.3mf`](models/design_front_bottom_cover.3mf) | 1 |  | Underbody protection panel |
| **Button Interface** | [`design_button_cap.3mf`](models/design_button_cap.3mf) | 1 |  | User interface button cap |

</div>

### **Performance Engineering Analysis**

**Drive Train Calculations**:
- **Motor Specification**: 1500 RPM N20 DC motor with quadrature encoder
- **Gear Reduction**: 26:25 ratio providing optimal speed-torque balance
- **Theoretical Maximum Velocity**: 1.72 m/s derived from wheel geometry and drive ratios
- **Operational Velocity**: 1.4 m/s selected for optimal control stability

**Structural Analysis**:
- **Motor Torque Capacity**: ~0.25 Nm at 6V, sufficient for 130g vehicle acceleration
- **Bearing System**: Four precision bearings minimizing rotational friction
- **Steering Load Management**: Mechanism optimized for servo torque characteristics
- **Impact Resistance**: Validated through comprehensive testing under competition conditions

### **Assembly Methodology**

<div align="center">
Assembly Process Documentation
</div>
<p align="center">
  <em>Staged assembly approach ensuring proper system integration and alignment</em>
</p>

**Assembly Sequence**:
1. **Drive System Integration**: Differential assembly and motor mounting with M2 hardware
2. **Steering Mechanism Installation**: Ackermann linkage and servo integration
3. **Wheel System Assembly**: Bearing installation and wheel mounting
4. **Electronic System Integration**: Pertinax board installation and component connection
5. **Final System Validation**: Comprehensive functional testing and alignment verification

---

## 💻 **Software Architecture** 

Our software implementation employs a distributed processing architecture that optimizes performance through specialized task allocation between multiple processors.

### **System Architecture Overview**

<table>
<tr>
<td width="60%">

**Processing Distribution**:
- **Vision Processing Unit**: STM32H747 handling real-time image analysis and high-level decision making
- **Sensor Fusion Unit**: nRF52832 managing multi-sensor data acquisition and preprocessing
- **Communication Bridge**: Bidirectional UART protocol at 115200 baud for inter-processor data exchange

**Core Software Components**:
- [`open.py`](src/open.py) - Open challenge navigation algorithms
- [`obstacle.py`](src/obstacle.py) - Obstacle challenge with integrated parking
- [`uart_slave.ino`](src/uart_slave.ino) - Sensor management firmware

</td>
<td width="40%">
Software Development Environment
<p align="center"><em>Integrated development and testing setup</em></p>
</td>
</tr>
</table>

### 💾 **Development Environment & Code Deployment**

#### **STM32H747 (Camera Microcontroller)**
- **Programming Language**: MicroPython for rapid development and testing
- **Development Interface**: Direct micro USB connection to evaluation board
- **Core Libraries**:
  - `machine` - Hardware abstraction for PWM, GPIO, and UART control
  - `pyb` - STM32-specific peripheral functions and timer management
  - `sensor` - Camera interface and real-time image processing

#### **nRF52832 (Sensor Microcontroller)**
- **Programming Language**: Arduino C++ for efficient sensor data handling
- **Development Interface**: Standard micro USB connection to evaluation board
- **Essential Libraries**:
  - `Wire.h` - I2C communication protocol for sensor networks

#### **Development Workflow Optimization**
We implemented magnetic USB connectors for the camera microcontroller, providing significant advantages during intensive development cycles. The magnetic interface enables rapid connection changes, prevents physical port damage from repeated use, and streamlines the programming and debugging process.

#### **Code Deployment Process**
1. **STM32H747 MicroPython Deployment**:
   - Transfer `.py` source files directly to microcontroller filesystem using magnetic USB connection
   - Automatic execution initialization from `main.py` on system startup
   - No compilation overhead - immediate interpreted execution for rapid iteration

2. **nRF52832 Arduino Deployment**:
   - Compile source code in Arduino IDE with nRF5 board package support
   - Upload compiled binary via micro USB interface to evaluation board
   - Precompiled firmware deployment ensuring reliable sensor operation

### 🎨 **Vision Processing Strategy**

We selected the **CIELAB color space** for its superior performance under variable lighting conditions compared to traditional RGB or HSV representations. Our custom MATLAB analysis tool systematically determines optimal detection thresholds.

**Technical Rationale**: LAB colorspace provides adequate performance for our application requirements, while machine learning approaches would introduce unnecessary complexity without significant benefits for this specific use case.

<div align="center">
Environmental Testing Validation
<p><em>Comprehensive testing under challenging lighting conditions including direct sunlight exposure</em></p>
</div>

### 🧭 **Navigation Algorithm Implementation**

#### **Open Challenge Navigation**

**State Machine Flow**:
```
Initial Forward → Follow Wall → Turn Corner → Follow Wall (repeat)
      ↑               ↑             ↑             ↑
  ToF + Color     Camera PID    IMU 90° Turn  Continue
  Detection      Wall Tracking                Navigation
```

**Open Challenge Pseudocode**:
```
INITIALIZE sensors, set direction = unknown
WHILE direction == unknown:
    DRIVE forward using IMU guidance
    DETECT orange/blue colors
    IF orange detected first: SET direction = clockwise
    IF blue detected first: SET direction = counterclockwise
    IF front ToF < 800mm: TRANSITION to wall following

WHILE corner_count < 12:
    FOLLOW inner wall using camera PID
    DETECT orange/blue corners
    IF corner detected: INCREMENT corner_count
    IF wall lost and min_distance traveled: EXECUTE 90° turn
    UPDATE odometry and heading

EXECUTE final forward movement
STOP
```

#### **Obstacle Challenge Strategy**

**Multi-State Operation**:
```
Determine Direction → Follow Color → Lost Color → Pass Color → U-Turn → Parking
        ↑                 ↑             ↑            ↑           ↑         ↑
   ToF + Color        Camera PID      Search      Avoidance   180° Turn  Magenta
   Detection          Color Track     Pattern     Maneuver    Maneuver   Detection
```

**Obstacle Challenge Pseudocode**:
```
INITIALIZE sensors
DETERMINE direction using side ToF sensors
EXECUTE initial alignment maneuver

WHILE corner_count < 13:
    NAVIGATE using camera color detection
    IF red detected: FOLLOW with right offset
    IF green detected: FOLLOW with left offset  
    IF color lost: SEARCH pattern
    IF color not found: PASS obstacle maneuver
    DETECT orange/blue corners for lap counting

EXECUTE 180° U-turn maneuver
APPROACH parking zone
DETECT magenta parking marker
EXECUTE parallel parking sequence
STOP
```

**Color-Specific Behaviors**:
- **Red Object Detection**: Right-side bias navigation with maintained offset
- **Green Object Detection**: Left-side bias navigation with maintained offset  
- **Position Maintenance**: Consistent pixel positioning for smooth obstacle tracking

### **Sensor Fusion Implementation**

**Data Integration Pipeline**:
```
nRF52832 Sensors ←→  UART  ←→ STM32H747 → Sensor Fusion → Control Decisions
     ↑                            ↑             ↑               ↓
  ToF Left                      Camera     PID Controller   Motor/Servo
  ToF Right                     Vision     State Machine     Actuators
 Encoder Data                  IMU Data
                               ToF Front
```

### **Control System Implementation**

**Steering Control Algorithm**:
```python
# PID controller implementation for smooth navigation
def calculate_steering_correction(vision_error, heading_error):
    proportional = vision_error * KP_GAIN
    integral = integrate_error(vision_error) * KI_GAIN  
    derivative = calculate_derivative(vision_error) * KD_GAIN
    return proportional + integral + derivative
```

### **Bidirectional Inter-Processor Communication**

**UART Protocol Specification**:
- **Baud Rate**: 115200 for optimal data throughput
- **Command Structure**: Single-character commands with formatted responses
- **Data Validation**: Checksum verification and timeout handling
- **Error Recovery**: Automatic reinitialization on communication failure

**Master (STM32H747) → Slave (nRF52832) Commands**:
- `'r'` - Request all sensor data (left_tof, right_tof, encoder)
- `'t'` - Request left ToF sensor only
- `'u'` - Request right ToF sensor only  
- `'e'` - Request encoder travel distance only
- `'z'` - Reset encoder counter to zero

**Slave Response Formats**:
- **All sensors**: `left_distance,right_distance,encoder_distance\n`
- **Left ToF only**: `left_distance\n`
- **Right ToF only**: `right_distance\n`
- **Encoder only**: `encoder_distance\n`

### **Parking Maneuver Analysis**

Our compact dimensions required innovative parking strategies to operate within the constrained parking space.

<div align="center">
Complex Parking Scenario
Simplified Parking Approach
</div>
<p align="center">
  <em>Parking strategy analysis for different final obstacle configurations</em>
</p>

### **Parallel Parking Strategy Optimization**

**🚧 Challenge**: Our compact 69mm vehicle length required extremely precise maneuvers within the tight 1.5× vehicle length parking space (103.5mm)

**💡 Initial Solution**: We designed a strategic front extension piece providing crucial benefits:

- **📏 Length Optimization**: 21mm extension increased total length to 90mm
- **Parking Space Compliance**: Requirement became 90mm × 1.5 = 135mm
- **Critical Clearance Design**: Narrow extension width allowed wall clearance during turns
- **🔄 Maneuverability Enhancement**: Additional space enabled reliable parking execution
**Multi-Stage Parking Sequence**:
1. **Approach Phase**: Follow magenta wall using camera guidance
2. **Turn-in Execution**: 80-degree turn outside parking spot
3. **Alignment Phase**: Odometry-based reverse positioning
4. **Reverse Maneuver**: Controlled backing for final alignment
5. **Straighten Phase**: Final orientation adjustment

> 💡🐜 ***Team Identity Discovery***: The distinctive front extension piece created a visual resemblance to an **ANT**'s mandible, perfectly aligning with our team name and establishing a memorable identity!
<p align="center">
  Original 69mm Vehicle in Parking Lot
  90mm Vehicle with Extension
</p>
<p align="center">
  <em>1) Original 69mm vehicle demonstrating parking constraints • 2) Extended 90mm vehicle with strategic front piece implementation</em>
</p>

**💡 Final Evolution**: After extensive testing, we iterated on the extension design to further enhance safety and performance:
- **📏 Enhanced Length**: Increased extension to 41mm for total vehicle length of 110mm
- **Parking Space Adjustment**: Expanded requirement to 110mm × 1.5 = 165mm
- **Improved Safety Margin**: Greater clearance for multi-turn maneuvers while maintaining higher speeds
- **Design Refinements**: Incorporated competition stickers creating "ANTi" branding and ant-inspired eyes
- **Maneuver Strategy**: Retained multiple-turn parking for optimal speed-safety balance
<p align="center">
  Final 110mm Vehicle in Extended Parking Lot
  Final Extension Design Detail
</p>
<p align="center">
  <em>1) Final 110mm vehicle in 165mm parking space with measurement verification • 2) Close-up of refined extension with custom branding and visual enhancements</em>
</p>

### Parallel Parking – Potential Improvements
- Pure vision-based parking using parking walls as obstacles → eliminates ToF distance dependency and works even if the parking zone is shifted elsewhere.
- Single-motion slow parking trajectory instead of safer fast three-segment → would save ~1.5 s .

### **Obstacle Navigation Patterns**

The algorithm handles all possible obstacle combinations through systematic pattern recognition and response.

<div align="center">
Clockwise Navigation Patterns
Counter-clockwise Navigation Patterns
</div>
<p align="center">
  <em>Comprehensive obstacle combination analysis for both navigation directions</em>
</p>

### **Vision Processing Pipeline**

1. **Image Capture**: 320×240 resolution at 26 frames per second
2. **Color Transformation**: RGB to LAB colorspace conversion
3. **Feature Detection**: Blob analysis with size and shape filtering
4. **Target Identification**: Largest valid blob selection for reliability
5. **Error Calculation**: Position deviation from desired tracking point

<div align="center">
Single Color Detection
Multi-Color Detection
</div>

### Software & Algorithms – Potential Improvements
- Replace hand-tuned PID with online adaptive gain scheduling based on lap time → we already have easy possible integration of lap-time logging via the nRF52832.
- Add optical flow (using the GC2145 bottom 80×80 pixels) for dead-reckoning backup when camera loses the line detection.
- Over-the-air firmware update via BLE (nRF52832) → Eliminates the need for cables during competition day, further improving ease of use compared to magnetic connections.

Complete software implementation details available in our [source code documentation](src/README.md).

---

## 📹 **Performance Videos** 

Our development process included precise testing and validation to ensure competition-ready performance across both challenge scenarios.

### **Competition Performance**

- **Open Challenge**: 16-second perfect score demonstration
- **Obstacle Challenge**: 35-second perfect score with integrated parking
- **Detection Reliability**: >95% accuracy across variable lighting conditions
- **System Responsiveness**: <50ms latency from detection to actuation

### **Video Documentation**

Complete performance demonstrations showcasing our vehicle's capabilities:

- **Open Challenge**  
  Open Challenge Video (https://youtu.be/tvqgwusap9M)  
  *Demonstrates autonomous navigation and speed control on a dynamic track.*

- **Obstacle Challenge**  
  Obstacle Challenge Video (https://youtu.be/fQPjyJrE8p8)  
  *Shows traffic sign detection, obstacle avoidance, optimal path planning and parallel parking with smooth obstacle following at consistent distances.*

**Media Production**: All logos and visual media edits were created by our team using the ***ibisPaint X*** mobile application. Video overlay commentary and caption explanation edits were also done by our team using ***CapCut*** for professional presentation of our performance videos.

---

## 🌐 **GitHub Utilization & Development** 

We leveraged GitHub as our central platform for comprehensive project management, version control, and public documentation, while maintaining a clean and professional repository history through our development workflow: working on local computers directly connected to our repository and committing changes only at significant milestones (e.g., completing the chassis design, integrating the vision system, finalizing obstacle navigation) to avoid disorganized overcommitting.

### **Development Workflow Strategy**

**Structured Development Approach**:
- **Local Development Environment**: Intensive development on local machines with feature branches
- **Milestone-Based Committing**: Strategic commits representing significant technical achievements
- **Quality Assurance**: Thorough testing and documentation before public repository updates
- **Clean Public History**: Professional repository showcasing polished development progression

**File Sharing and Public Updates**: All project assets, CAD files (`models/`), schematics (`schemes/`), source code (`src/`), and GitHub documentation are shared publicly at each milestone. Before pushing updates, we cleaned up our progress, data, and results to ensure the public repository reflects a safer and smoother development process than our local workflow, making it easier for others to understand and replicate. Additionally, we record the date and time of the last updates in the README documents, providing easy access to the commit date and version.

### **Commit History & Project Evolution**

Our development timeline from March to November 2025 demonstrates consistent progress and systematic engineering:

**Key Development Milestones**:
- **March 2025**: Repository initialization and project structure establishment
- **May 2025**: Core mechanical design and electronic system implementation  
- **October 2025**: International competition preparation and system optimization
- **November 2025**: Final documentation, performance tuning, and competition readiness

**Commit Philosophy**: Each of our 20+ commits represents substantial technical progress, including:
- Complete mechanical system implementations (`design_base.3mf`, `4_gear_differential.3mf`)
- Electronic schematic and wiring documentation (`wiring_diagram.jpg`)
- Software algorithm development and optimization (`open.py`, `obstacle.py`)
- Comprehensive technical documentation updates across all 8 specialized folders
- Performance validation and testing results with competition videos

### **Repository Organization Excellence**

**Comprehensive Documentation Structure**:
- **8 Specialized Folders**: Each containing detailed technical README documentation
- **Structured File Organization**: Logical grouping of related technical assets
- **Professional Presentation**: Clean, well-organized repository layout
- **Easy Navigation**: Intuitive structure for both technical judges and future developers

### **Supporting Future Development & Replication**

<div align="center">

## 🔧 **EASY REPLICATION & FUTURE DEVELOPMENT**

### **Our documentation enables effortless duplication by other teams and developers**

</div>

**Replication-Focused Design**:
- **Complete Bill of Materials**: All components clearly specified with datasheet information
- **Step-by-Step Assembly Guides**: Detailed instructions for mechanical and electronic assembly
- **Manufacturing Files**: 3MF format for universal 3D printing compatibility
- **Source Code Availability**: Complete software implementation with detailed comments and explanations
- **Troubleshooting Guidance**: Solutions to common implementation challenges

**Supporting Others and Future Development**: While we do not want others to simply copy our work for private or closed-source use, we intentionally chose the AGPL-3.0 license to ensure that any future developments based on our code, robot design, hardware system, or overall architecture remain open-source. This strong copyleft license guarantees that improvements or adaptations, whether for competition, education, or research, must also be shared with the community. We are inviting others to replicate, modify, or build upon our work. The modular design of our system and detailed documentation make it easy to adapt the robot for different challenges. Contributions and suggestions, such as adding multi-robot coordination or advanced path-planning, are welcome via GitHub issues.

**Future Development Pathways**:
- **Modular Architecture**: Easy component upgrades and system modifications using our socket-based design
- **Comprehensive Documentation**: Every design decision and implementation detail documented
- **Open Source Philosophy**: AGPL-3.0 license ensuring continued community access
- **Educational Focus**: Detailed explanations of engineering principles and design choices

### **GitHub Best Practices Implementation**

**Professional Repository Management**:
- **Regular Updates**: Consistent documentation improvements and technical refinements
- **Quality Standards**: High-quality images, professional diagrams, and clear technical writing
- **Accessibility**: Well-structured content suitable for both technical and non-technical audiences
- **Completeness**: Every aspect of the project thoroughly documented and accessible

**Documentation Excellence Standards**:
- ✅ **Complete Information**: Comprehensive coverage of all technical aspects across 8 specialized folders
- ✅ **Structured Organization**: Logical, easy-to-navigate repository structure with clear documentation hierarchy
- ✅ **Regular Commits**: Meaningful, milestone-based version control demonstrating systematic development
- ✅ **Enhanced Engineering Understanding**: Detailed design rationale and implementation insights exceeding basic requirements

---

## 📜 **License & Replication** 

### **Open Source Philosophy for Community Advancement**

**Replication-Focused Documentation**:
- **Complete Technical Transparency**: Every design decision and implementation detail documented
- **Manufacturing Accessibility**: Use of widely available components and custom manufacturing methods
- **Educational Value**: Detailed explanations enabling understanding of engineering principles
- **Future Development**: Clear pathways for system improvements and modifications

This project is licensed under the **GNU Affero General Public License v3.0 (AGPL-3.0)** to promote open collaboration, ensure continued community access to derivative works, facilitate easy replication by future developers and competition teams, and foster ongoing innovation through publicly accessible developments.

```
GNU Affero General Public License v3.0

Copyright (C) 2025 Atakan Ersoy (atakanersoy)

This program is free software: you can redistribute it and/or modify
it under the terms of the GNU Affero General Public License as published
by the Free Software Foundation, either version 3 of the License, or
(at your option) any later version.

This program is distributed in the hope that it will be useful,
but WITHOUT ANY WARRANTY; without even the implied warranty of
MERCHANTABILITY or FITNESS FOR A PARTICULAR PURPOSE. See the
GNU Affero General Public License for more details.

You should have received a copy of the GNU Affero General Public License
along with this program. If not, see <https://www.gnu.org/licenses/>.
```

### **Comprehensive Documentation Access**

<div align="center">

## 📚 **DETAILED TECHNICAL DOCUMENTATION**

### **Explore our specialized documentation for complete technical details**

</div>

- **For mechanical design and 3D models**: [Models Documentation](models/README.md)  
- **For electrical schematics and wiring**: [Schemes Documentation](schemes/README.md)  
- **For software implementation and algorithms**: [Software Documentation](src/README.md)  
- **For competition performance videos**: [Video Documentation](video/README.md)  
- **For additional resources and photos**: [Other Documentation](other/README.md)
- **For MATLAB vision tools**: [MATLAB Documentation](matlab/README.md)
- **For team information**: [Team Photos Documentation](t-photos/README.md)
- **For vehicle documentation**: [Vehicle Photos Documentation](v-photos/README.md)

---

<div align="center">

## 🎯 **Prepared for International Competition Excellence**

**Team ANTi - *Never Stop Developing Unless We Stop Learning***

### **Comprehensive documentation enabling easy replication and future development**




</div>

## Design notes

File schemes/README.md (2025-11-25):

# Schemes Documentation

This folder contains the complete electrical schematics, wiring diagrams, and power management documentation for Team ANTi's WRO 2025 Future Engineers robot. All electronic systems were designed, manufactured, and assembled by our team using custom pertinax boards to achieve optimal performance in the world's smallest autonomous vehicle. This documentation was last updated on **Saturday, November 08, 2025, at 06:41 PM +03**.

## 🎯 Electrical Design Philosophy

Our electrical design philosophy emphasizes **modularity, maintainability, and hands-on engineering excellence**. By choosing custom pertinax board construction over professionally manufactured PCBs, we achieved complete control over the manufacturing process while developing essential engineering skills through practical implementation.

## 📋 Complete Bill of Materials (BOM)

| Component | Image | Quantity | Type | Description |
|---|---|---|---|---|
| STM32H747 | Camera Microcontroller | 1 | Camera Microcontroller | Dual-core high-performance microcontroller for vision processing |
| nRF52832 | Sensor Microcontroller | 1 | Sensor Microcontroller | Handles sensor computations and data processing |
| GC2145 Camera | Camera | 1 | 2MP Camera | 2MP CMOS camera, 2.2mm focal length, 80° view angle |
| VL53L1X ToF | ToF Sensor | 1 | ToF Sensor | 400cm range, full FoV - used for front detection |
| VL53L3CX ToF | ToF Sensor | 2 | ToF Sensor | 700cm range, narrow FoV with window lens - used for side detection |
| LSM6DSOX IMU | IMU | 1 | 6-axis IMU | Accelerometer and gyroscope for navigation |
| DRV8833 Driver | Motor Driver | 1 | Motor Driver | PWM motor driver for DC motor control |
| BOB-12009 | Logic Level Converter | 1 | Logic Level Converter | 3.3V–5V bidirectional voltage conversion |
| SX1308 Booster | Voltage Booster | 1 | Voltage Booster | 2A DC-DC step-up converter for motor power |
| Feetech FS0307 | Servo Motor | 1 | Servo Motor | Submicro servo for steering mechanism |
| 1500 RPM N20 | DC Motor + Encoder | 1 | DC Motor + Encoder | Brushed DC motor with Hall effect encoder |
| Power-Xtra PX103035 | LiPo Battery | 1 | LiPo Battery | 3.7V 1000mAh battery with PCM protection |
| LiPo Rider Plus | Charger/Booster | 1 | Charger/Booster | USB-C power management with switching |
| KLS7-TS1204 | Tactile Switch | 1 | Tactile Switch | Start action initiation button |
| LEGO 87697 | Tire | 4 | Tire | 21mm diameter, 12mm width with center ridge |

**Component Sourcing Philosophy**: No direct product links or prices are provided to maintain universal accessibility and prevent outdated information. All components are easily searchable online using the provided names and images, with authenticity verifiable through the datasheets in this repository.

## 🔌 Complete Wiring System

### Master Wiring Schematic & Physical Implementation

<p align="center">
  <a href="wiring_diagram.jpg" target="_blank">
    Hand-Drawn Wiring Diagram
  </a>
  Physical Implementation
</p>
<p align="center">
  <em>1) Complete hand-drawn and digitally traced professional wiring schematic showing all electrical connections (<a href="wiring_diagram.jpg" target="_blank">view full resolution</a>) • 2) Physical implementation demonstrating socket-based construction of the schematic</em>
</p>

**Engineering Documentation Excellence**:
- **Professional Schematic**: Every connection meticulously documented with color-coded wiring traces
- **Socket-Based Architecture**: All components use removable sockets for easy maintenance and testing
- **Cable Management**: Strategic routing through multiple pertinax holes prevents stress points by distributing cable stress and minimizing bending at any single point, ensuring long-term reliability
- **Visual Verification**: Direct correlation between schematic and physical implementation

**Cable Management**:

The cable management strategy was specifically designed to prevent socket cables from bending excessively and causing breakpoints or connection issues, we implemented a strategic cable routing approach. Each cable passes through two different pertinax holes, distributing stress and minimizing bending at any single point, ensuring long-term reliability.

## ⚡ Power Management System

### Power Distribution Architecture

**Multi-Rail Power System**:
- **+3V3 Rail**: Primary power for microcontrollers, sensors, and ToF sensors (STM32H747, nRF52832, VL53L3CX)
- **+5V Rail**: Servo power (Feetech FS0307) and SX1308 booster input
- **+6V Rail**: DC motor power through SX1308 booster (1500 RPM N20 motor)
- **+2V8 Rail**: Powers the GC2145 camera and VL53L1X ToF sensor
- **+1V8 Rail**: Low-power analog components (LSM6DSOX IMU)

### Power Consumption Analysis

**Battery Performance Specifications**:
- **Capacity**: 1000mAh 3.7V LiPo with PCM protection
- **Run Time**: 4–5 hours under typical operational load
- **Charge Time**: ~45 minutes via USB-C at 10W (2A) maximum input
- **Calculation Basis**: Run time = Battery Capacity (mAh) / Total System Current (mA)

**Power Consumption Breakdown**:
| Component | Voltage | Typical Current | Peak Current | Power Consumption |
|---|---|---|---|---|
| STM32H747 | 3.3V | 25 mA | 80 mA | 83 mW - 264 mW |
| nRF52832 | 3.3V | 4 mA | 10 mA | 13 mW - 33 mW |
| GC2145 Camera | 2.8V | 25 mA | 60 mA | 70 mW - 168 mW |
| VL53L1X ToF | 2.8V | 10 mA | 20 mA | 28 mW - 56 mW |
| VL53L3CX ToF (x2) | 3.3V | 12 mA each | 25 mA each | 79 mW - 165 mW |
| LSM6DSOX IMU | 1.8V | 0.5 mA | 1.2 mA | 0.9 mW - 2.2 mW |
| Feetech FS0307 Servo | 5V | 3 mA (idle) | 100 mA (stall) | 15 mW - 500 mW |
| SX1308 Booster Input | 5V | 40 mA | 200 mA | 200 mW - 1500 mW |
| 1500 RPM N20 Motor | 6V | 30 mA | 250 mA | 180 mW - 1500 mW |
| **Total System** | **Mixed** | **~120 mA** | **~500 mA** | **~0.5W - 2.5W** |

**Operational Power Validation**: 
- **Typical Operation**: 0.5W - 1.2W during normal autonomous navigation
- **Peak Operation**: 1.8W maximum observed during intensive processing and motor activity
- **Measurement Method**: USB-C power meter confirmation of calculated estimates

## 🔧 Custom Manufacturing Philosophy

### Why Pertinax Over Professional PCBs

<p align="center">
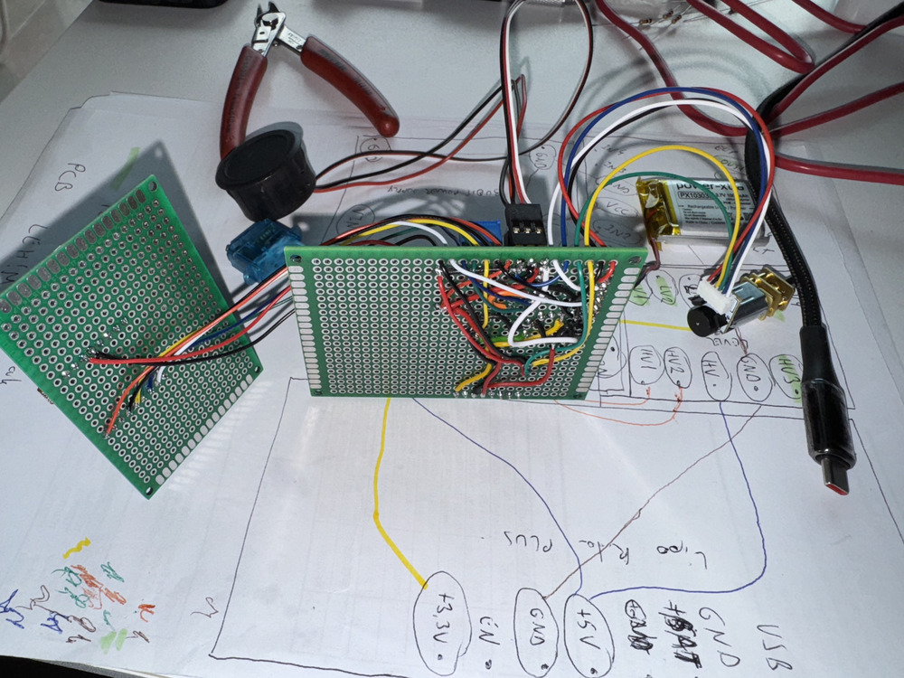
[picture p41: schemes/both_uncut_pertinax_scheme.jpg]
Raw Pertinax Material
  
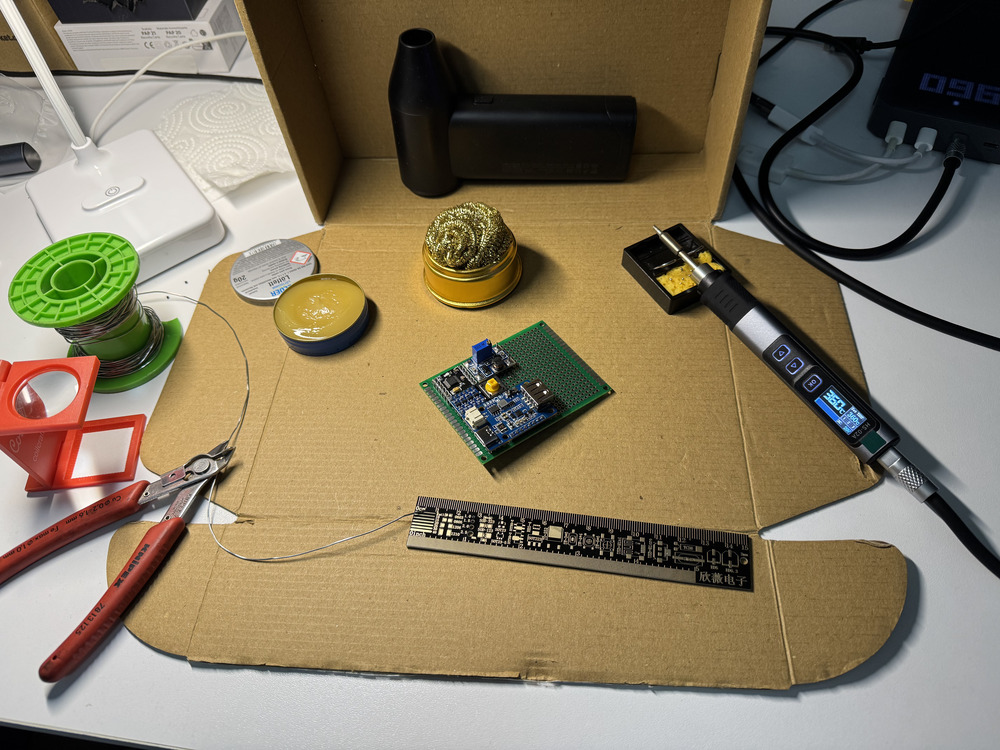
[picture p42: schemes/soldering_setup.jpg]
Hands-On Manufacturing
  
</p>
<p align="center">
  <em>1) Pertinax boards before custom shaping • 2) Complete soldering setup used for all custom manufacturing</em>
</p>

**Strategic Engineering Choice Analysis**:

| Aspect | Professional PCB | Custom Pertinax | Our Rationale |
|---|---|---|---|
| **Development Speed** | 1-2 weeks turnaround | Instant modifications | Rapid prototyping and iterative improvement |
| **Cost Efficiency** | $5-$25 per iteration | <$5 total material cost | Budget-friendly for student teams |
| **Design Flexibility** | Fixed once manufactured | Adjustable in minutes | Accommodates component changes |
| **Skill Development** | Limited hands-on experience | Comprehensive soldering and circuit design | Essential engineering skill building |
| **Maintenance** | Difficult component replacement | Easy socket-based swapping | Competition-ready serviceability |
| **Control** | Outsourced manufacturing | Complete in-house control | Understanding every connection |

**Socket-Based Design Advantages**:
- **Component Testing**: Individual modules can be tested independently
- **Field Repairs**: Quick replacement during competition without soldering
- **Upgrade Path**: Easy component upgrades as technology evolves
- **Educational Value**: Visual understanding of circuit relationships

## 🎯 Component-Specific Engineering

### Microcontroller Systems

<p align="center">
  STM32H747 Connections
  nRF52832 Connections
</p>
<p align="center">
  <em>1) STM32H747 camera microcontroller with peripheral connections • 2) nRF52832 sensor microcontroller interface details</em>
</p>

**STM32H747 Camera Microcontroller**:
- **Architecture**: Dual-core Cortex-M7/M4 for parallel vision and control processing
- **Connectivity**: Dedicated camera interface (DCMI) for GC2145, multiple UART/I2C for sensors
- **Power Management**: Separate 3.3V rail with decoupling capacitors for stable operation
- **Integrated Power Regulation**: Built-in 1.8V and 2.8V rails generated on the STM32 evaluation board for camera and sensor peripherals

**nRF52832 Sensor Microcontroller**:
- **Role**: Dedicated sensor fusion and real-time data processing
- **Communication**: I2C for ToF sensors, UART to STM32H747
- **Efficiency**: Low-power operation for extended battery life

### Vision System: GC2145 Camera

**Technical Specifications**:
- **Resolution**: 2MP (1600×1200) for detailed track detection
- **Optics**: 2.2mm focal length with 80° diagonal field of view
- **Distortion**: <1.0% barrel distortion for accurate object following
- **Power**: 2.8V analog core with 3.3V digital I/O
- **Interface**: DCMI parallel interface compatible with STM32H747

<p align="center">
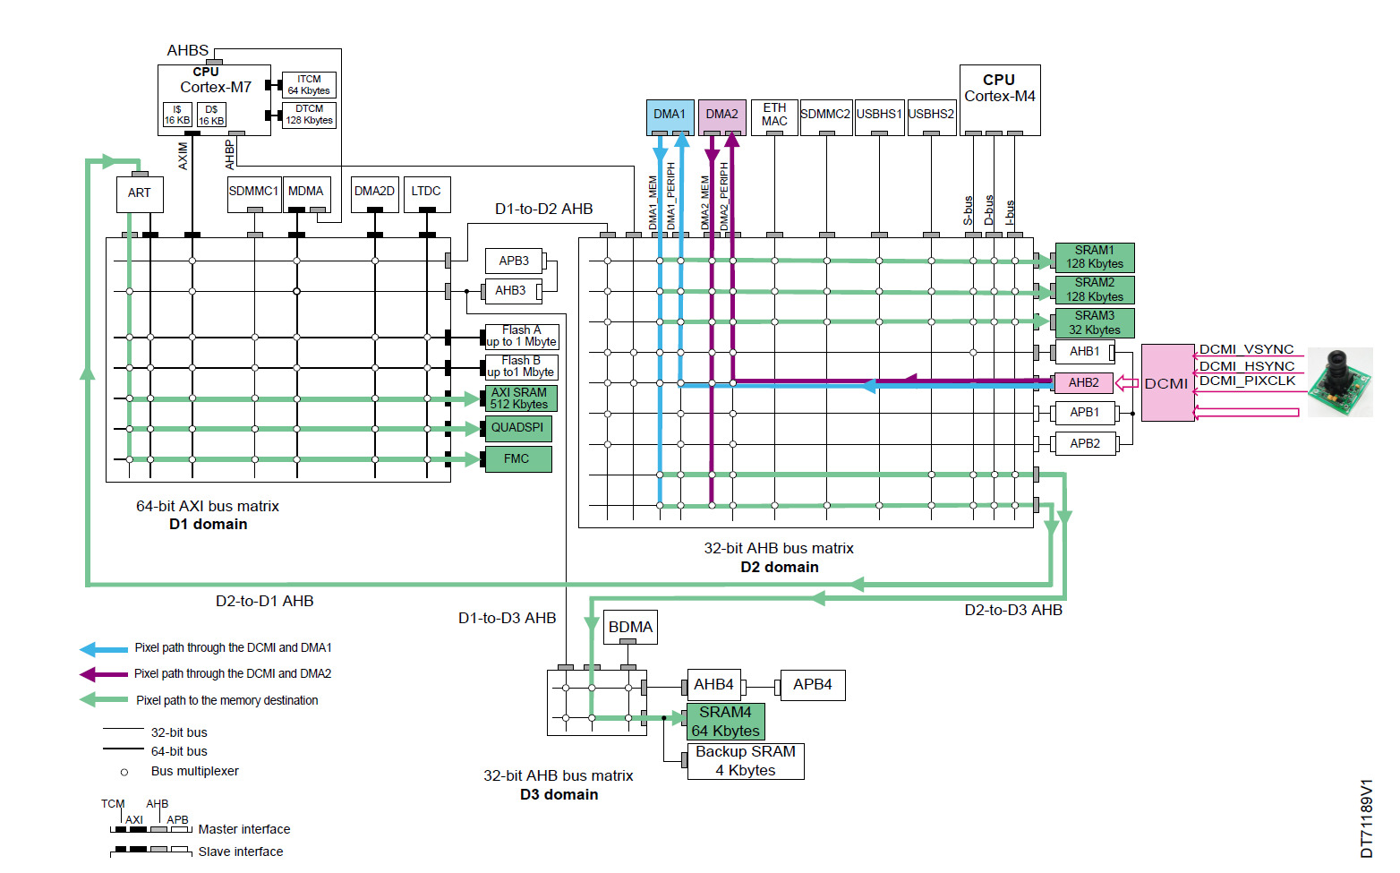
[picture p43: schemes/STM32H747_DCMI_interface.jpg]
DCMI Interconnection
  
</p>
<p align="center">
  <em>DCMI interconnection and data path in the STM32H745/755 and STM32H747/757 devices. The DMA1 and DMA2 in the D2 domain can access slaves in the D1 and D3 domains, allowing efficient data transfer from the DCMI to the respective memories.</em>
</p>

**Performance Features**:
- **Low-Light Capability**: Enhanced sensitivity for competition lighting variations
- **Frame Rate**: Configurable up to 30fps for real-time processing
- **Integration**: Direct connection to STM32H747 DCMI interface without intermediate conversion

### Time-of-Flight Sensor System

**ToF Sensor Power Distribution**:
- **VL53L1X**: Powered from +2V8 rail (front sensor)
- **VL53L3CX**: Powered from +3V3 rail (side sensors with window lenses)

#### ToF Sensor Comparison & Selection

<p align="center">
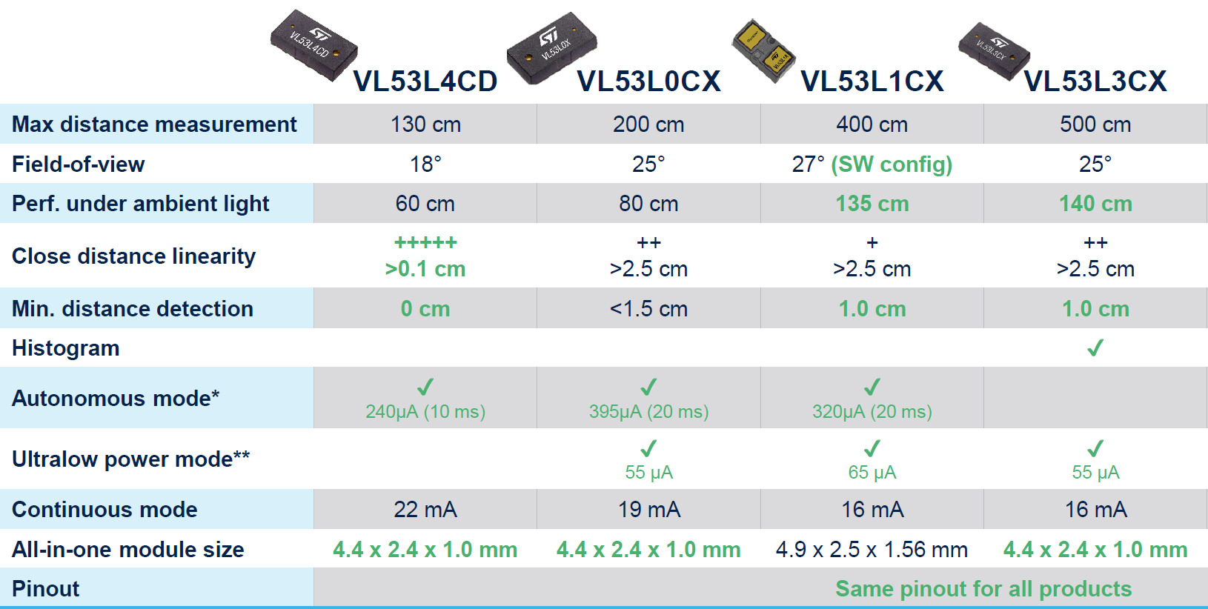
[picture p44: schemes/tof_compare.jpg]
ToF Sensor Comparison
  
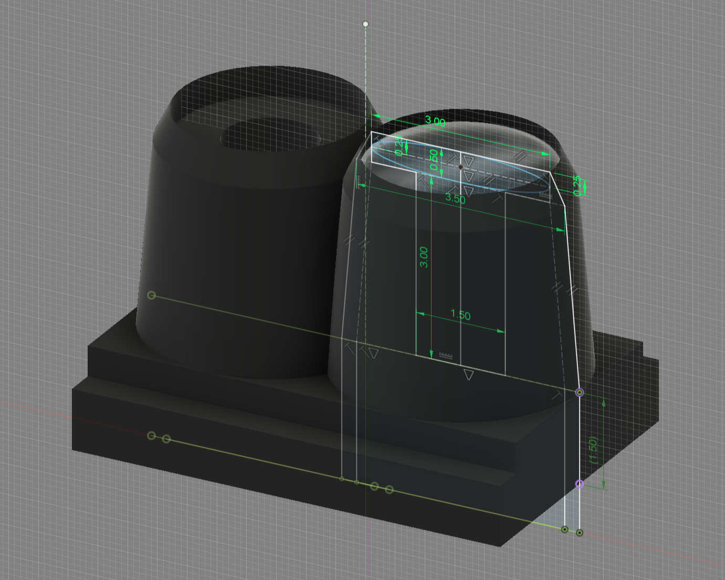
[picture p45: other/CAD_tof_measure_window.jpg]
Window Lens Design
  
</p>
<p align="center">
  <em>1) VL53L1CX vs VL53L3CX performance comparison showing detailed specifications • 2) Dimensions and specifications of the ToF window lens used for narrower FoV optimization</em>
</p>

**Technical Specification Comparison**:

| Parameter | VL53L1CX (Front) | VL53L3CX (Sides) |
|---|---|---|
| **Max Distance** | 400 cm | 500 cm |
| **Field of View** | 27° (software configurable) | 25° (fixed) |
| **Ambient Light Performance** | 135 cm | 140 cm |
| **Close Distance Linearity** | +>2.5 cm | ++>2.5 cm (improved) |
| **Minimum Distance** | 1.0 cm | 1.0 cm |
| **Histogram Processing** | No | Yes (advanced filtering) |
| **Autonomous Mode** | Yes, 320 μA @20ms | No |
| **Ultra-low Power** | 65 μA | 55 μA |
| **Continuous Mode** | 16 mA | 16 mA |
| **Sensor Size** | 4.9×2.5×1.56 mm | 4.4×2.4×1.0 mm |
| **Pin Compatibility** | Identical pinouts | Identical pinouts |

**Sensor Selection Rationale**: VL53L1CX chosen for front detection with configurable FoV, while VL53L3CX selected for side detection benefiting from longer range and decreased FoV with window lenses compatible with VL53L3CX sensor dimensions and optics, achieving even narrower field of view for improved accuracy in challenging conditions.

#### Field of View Engineering Challenge

<p align="center">
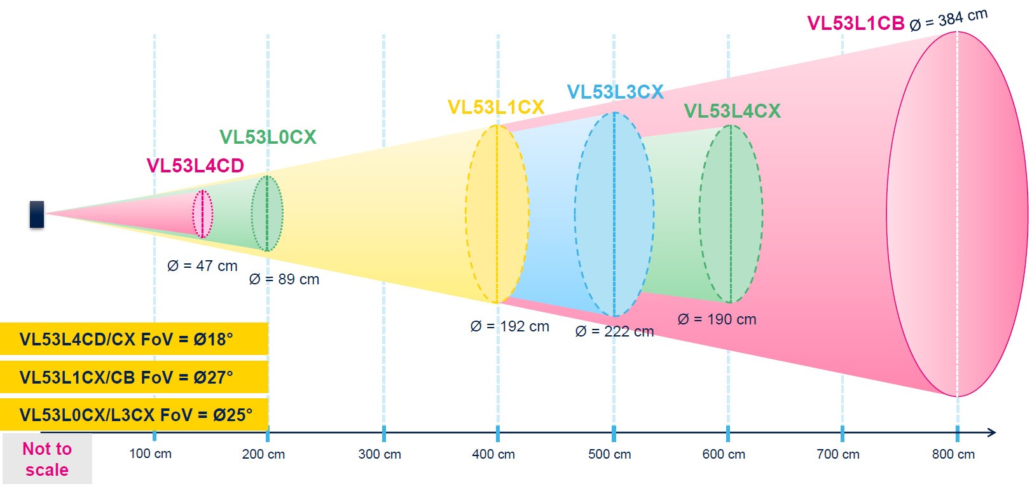
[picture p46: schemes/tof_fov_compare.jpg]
ToF FoV Analysis
  
</p>
<p align="center">
  <em>Field of view analysis showing ground intersection problem at extended ranges</em>
</p>

**Problem Identification**:
- **Ground Intersection**: At medium ranges, FoV cones intersect with ground surface
- **VL53L1CX**: 192cm diameter at 400cm range (27° FoV)
- **VL53L3CX**: 222cm diameter at 500cm range (25° FoV)
- **Robot Constraints**: Minimal height (57mm) forces low sensor mounting

**Engineering Solutions**:
1. **Angular Adjustment**: Sensors mounted with slight upward tilt to increase ground intersection distance
2. **Window Lens Implementation**: Window lenses reduce effective FoV for longer clear detection
3. **Threshold Optimization**: Software filters for reliable object detection beyond ground interference

**Result**: Extended usable detection range from ~150cm to ~300cm for side sensors

#### ToF Schematic

<p align="center">
  ToF Sensor Schematic
</p>
<p align="center">
  <em>ToF sensor schematic illustrating connections and layout for the VL53L1X and VL53L3CX sensors with only the input voltage different.</em>
</p>

### Motor Control Systems

<p align="center">
  Motor Driver Circuit
  Servo Control
</p>
<p align="center">
  <em>1) DRV8833 motor driver with SX1308 voltage boosted input • 2) Feetech FS0307 servo with logic level conversion</em>
</p>

**DC Motor Drive System**:
- **Motor Specification**: 1500 RPM N20 DC motor with Hall effect magnetic quadrature encoder
- **Voltage Optimization**: SX1308 booster provides stable 6V to motor driver for consistent performance
- **Logic Level**: DRV8833 operates with 3.3V control signals from microcontroller
- **Power Architecture**: SX1308 receives 5V input and provides 6V output to motor driver
- **Speed Calculation**: 
  - Gear Reduction: 26:25 ratio through custom spur gear design
  - Wheel RPM: 1500 × (26/25) = 1560 RPM
  - Theoretical Maximum Speed: 1.72 m/s with 21mm diameter wheels
  - Operational Speed: 1.4 m/s via PWM control for optimal stability

**Servo Control System**:
- **Logic Level Conversion**: BOB-12009 converts 3.3V microcontroller signals to 5V servo requirements
- **Precision Control**: PWM signal conditioning for accurate Ackermann steering positioning
- **Power Isolation**: Separate power rail prevents servo noise affecting sensitive sensors

#### Motor & Encoder Schematic

<p align="center">
  Motor and Encoder Schematic
</p>
<p align="center">
  <em>Motor and encoder schematic showing the integration of the motor with Hall effect encoder.</em>
</p>

### Power Management Components

<p align="center">
  Power Management
  Voltage Boosting
</p>
<p align="center">
  <em>1) LiPo Rider Plus charging and distribution system • 2) SX1308 voltage booster for motor power</em>
</p>

**LiPo Rider Plus Power Management**:
- **Charging**: USB-C input with 2A maximum charging current
- **Power Switching**: Integrated switch controls all power rails after modification
- **Battery Protection**: PCM integration for over-current and over-discharge protection

**SX1308 Voltage Booster**:
- **Input**: 5V from LiPo Rider Plus
- **Output**: Stable 6V for DC motor operation
- **Current Capacity**: 2A maximum supporting motor peak demands
- **Efficiency**: >90% conversion efficiency minimizing power loss

## 🛠️ Engineering Challenges & Solutions

### Power Management Breakthrough

With our components selected, we faced significant challenges in power distribution and management. During development, we encountered a critical power management issue where the 3.3V rail remained active when system was switched off, causing battery drain.

**Root Cause Analysis**:
- LiPo Rider Plus power switch only controls 5V output
- 3.3V LDO regulator connected directly to battery voltage
- System drawing ~5mA even when "off"

While reading the datasheets, we discovered that the power switch on the LiPo Rider Plus only controls the 5V output. After diving deep into the component's schematic, we figured out that the 3.3V output was derived directly from the 3.7V battery connected to an LDO regulator (low-dropout regulator). Further research into the LDO specifications revealed that 5V input for the LDO is also applicable to receive optimal ~3.3V output.

**Innovative Hardware Solution**:
1. **Component Modification**: Desoldered unused USB-A input port
2. **LDO Reprogramming**: Lifted input pin from battery connection
3. **Insulation**: Kapton tape prevention of unwanted connections
4. **Rewiring**: Connected LDO input to switched 5V rail

Our solution involved desoldering the unused but mounted USB-A input of the LiPo Rider Plus, then lifting the LDO by desoldering the input pin from the battery voltage. We applied Kapton tape to prevent any unwanted electrical connections and soldered the LDO input to the 5V output directly from the USB-A's mounted pin. This innovative fix ensured that all power rails are controlled by the LiPo Rider Plus power switch.

<p align="center">
  Power Switch Modification
</p>
<p align="center"><em>Complete hardware modification ensuring all power rails are switch-controlled</em></p>

**Result**: True power-off state with zero battery drain, extending standby time indefinitely

### Thermal Management Validation

Although we thoroughly researched all datasheets and specifications, we conducted comprehensive thermal testing to ensure system reliability under extended operation. Our thermal analysis confirmed optimal operating temperatures across all critical components:

<p align="center">
<table align="center">
<tr>
<td align="center"><br><strong>Battery: 25°C</strong></td>
<td align="center"><br><strong>Microcontroller: 37°C</strong></td>
</tr>
<tr>
<td align="center"><br><strong>Motor: 29°C</strong></td>
<td align="center"><br><strong>Power Management: 27°C</strong></td>
</tr>
</table>
</p>
<p align="center"><em>Infrared thermal imaging results demonstrating stable thermal performance during maximum operational load</em></p>

**Testing Methodology**:
- **Conditions**: Extended operation under maximum processing load
- **Measurement**: Infrared thermal imaging at component surfaces
- **Validation**: All temperatures within safe operating ranges
- **Margin**: Significant thermal headroom for competition conditions

**Key Findings**: All critical components operate well within safe temperature limits, with the highest temperature observed at the microcontroller (37°C) during intensive processing. The battery maintains a cool 25°C, confirming efficient power distribution and minimal heat generation throughout the system.

### Double-Layer Board Innovation

Our compact design required innovative board manufacturing solutions to fit all electronics within the minimal footprint. Facing extreme space constraints, we developed an innovative double-layered pertinax board solution inspired by multi-layer PCB manufacturing. We successfully managed to achieve a custom self-made double-layered pertinax connection on the same board, developing all our electronic boards using our own equipment instead of external manufacturing.

**This hands-on approach significantly enhanced our engineering knowledge and provided invaluable practical experience in custom board design and fabrication.**

<p align="center">
  Double Layer Design
</p>
<p align="center"><em>Our custom self-made double-layered pertinax board with mounted second-layer components</em></p>

<table>
<tr>
<td width="60%">
To prevent potential short circuits and thermal issues between layers, we applied Kapton tape insulation on the bottom of top-layer components, ensuring reliable electrical isolation.<br><br>

**Space Optimization Strategy**:
- **Insulation Solution**: Kapton tape between layers prevents electrical contact
- **Structural Integrity**: Strategic component placement maintains board rigidity
- **Accessibility**: All test points and connections remain accessible
</td>
<td width="30%">
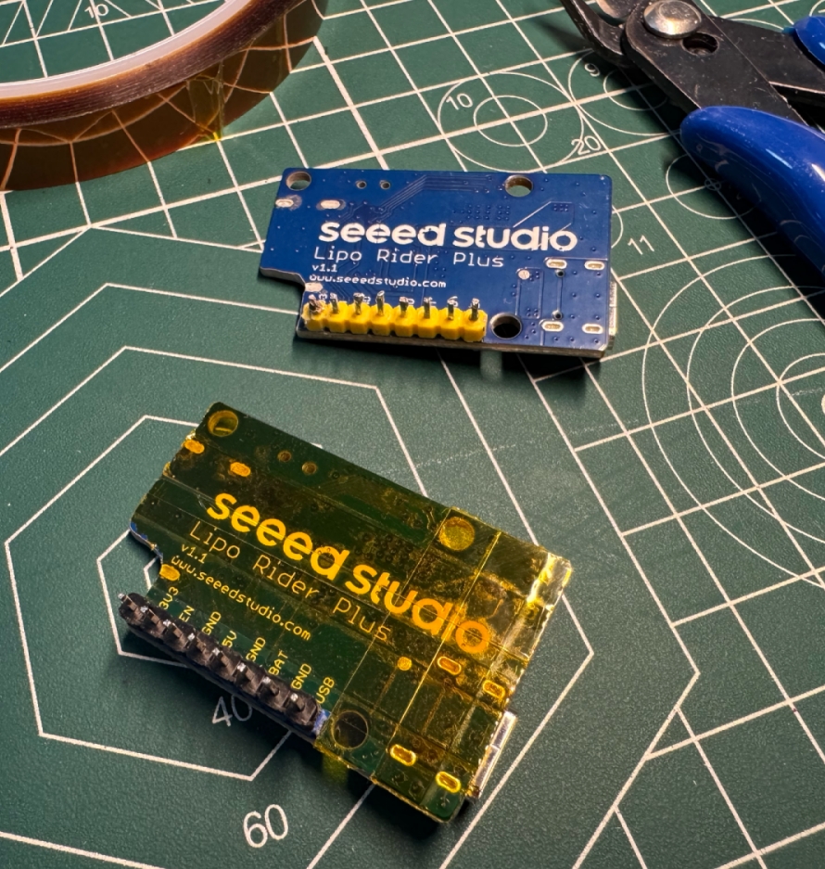
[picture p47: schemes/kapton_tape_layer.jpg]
Kapton Tape Insulation

<p align="center"><em>Kapton tape insulation applied to prevent layer contact</em></p>
</td>
</tr>
</table>

## 🔌 Interface & Control Systems

<p align="center">
  Start Button
  Logic Level Conversion
</p>
<p align="center">
  <em>1) Tactile start button with direct connection to microcontroller • 2) BOB-12009 logic level converter implementation</em>
</p>

**User Interface**:
- **Start Mechanism**: KLS7-TS1204 tactile switch with direct pin-to-GND connection
- **Visual Feedback**: Software includes visual feedback and debounce logic
- **Safety**: Momentary action design helps prevent accidental operation. The switch is active low, meaning it triggers the mechanism when pressed, ensuring that operation only occurs during intentional activation.

**Signal Conditioning**:
- **Voltage Compatibility**: BOB-12009 ensures reliable 3.3V to 5V signal conversion for servo motor control
- **Noise Immunity**: Proper decoupling and signal integrity maintenance
- **Control Signal Support**: Facilitates effective control of the servo motor by ensuring proper voltage levels

## 📚 Datasheet References

All component specifications are thoroughly documented in the following datasheets:

| Component | Datasheet File | Key Specifications |
|---|---|---|
| **BOB-12009 Logic Converter** | [BOB-12009.pdf](BOB-12009.pdf) | 3.3V-5V bidirectional conversion |
| **DRV8833 Motor Driver** | [drv8833.pdf](drv8833.pdf) | PWM motor control, current limiting |
| **Feetech FS0307 Servo** | [FS0307-specs.pdf](FS0307-specs.pdf) | Submicro size servo, torque specifications |
| **GC2145 Camera** | [GC2145.pdf](GC2145.pdf) | 2MP resolution, interface timing |
| **KLS7-TS1204 Switch** | [kls7-ts1204.pdf](kls7-ts1204.pdf) | Tactile button characteristics |
| **LiPo Rider Plus** | [LiPoRiderPlus_ETA9740_V1.1.pdf](LiPoRiderPlus_ETA9740_V1.1.pdf) | Charging IC specifications |
| **LiPo Rider Plus Schematic** | [LiPoRiderPlus_SCH.pdf](LiPoRiderPlus_SCH.pdf) | Board layout and connections |
| **LSM6DSOX IMU** | [lsm6dsox.pdf](lsm6dsox.pdf) | 6-axis motion tracking |
| **N20 Motor** | [N20_motors.pdf](N20_motors.pdf) | Motor and encoder specifications |
| **nRF52832 Microcontroller** | [nRF52832.pdf](nRF52832.pdf) | Pin interfaces that handle sensor computations |
| **STM32H747 Microcontroller** | [stm32h747.pdf](stm32h747.pdf) | Dual-core architecture, peripherals |
| **SX1308 Booster** | [SX1308.pdf](SX1308.pdf) | DC-DC step-up converter |
| **VL53L1X ToF Sensor** | [vl53l1x.pdf](vl53l1x.pdf) | 400cm range, full FoV operation |
| **VL53L3CX ToF Sensor** | [vl53l3cx.pdf](vl53l3cx.pdf) | 500cm range, with smaller FoV |

## ✅ Engineering Validation

This comprehensive electrical and schematic documentation provides complete transparency into our design process, component selection rationale, manufacturing methodology, and problem-solving approaches. Every aspect of our electrical system has been optimized for reliability, maintainability, and performance in the WRO 2025 Future Engineers competition.

**Documentation Completeness**: All schematics, wiring diagrams, component specifications, and implementation details are provided to enable exact replication of our electrical systems. This documentation aims to fulfill the WRO Future Engineers competition requirements for comprehensive engineering documentation through detailed electrical system transparency.

---

For mechanical design and 3D models: [Models Documentation](../models/README.md)  
For software implementation and algorithms: [Software Documentation](../src/README.md)  
For competition performance videos: [Video Documentation](../video/README.md)  
For additional resources and photos: [Other Documentation](../other/README.md)

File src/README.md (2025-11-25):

# Software Documentation

This folder contains the complete source code for Team ANTi's WRO 2025 Future Engineers robot, written in **MicroPython** for the STM32H747 camera microcontroller and **Arduino C++** for the nRF52832 sensor microcontroller. This documentation was last updated on **Saturday, November 09, 2025, at 04:48 AM +03**.

<table>
<tr>
<td width="60%">

## 🎯 Software Architecture Overview

Our software system implements a distributed architecture with two microcontrollers communicating via UART protocol:

- **STM32H747 (Camera MCU)**: Runs MicroPython for high-level navigation, computer vision, and main control logic
- **nRF52832 (Sensor MCU)**: Runs Arduino C++ for real-time sensor data acquisition and preprocessing
- **Bidirectional UART Communication**: 115200 baud rate for seamless data exchange between processors

</td>
<td width="40%">
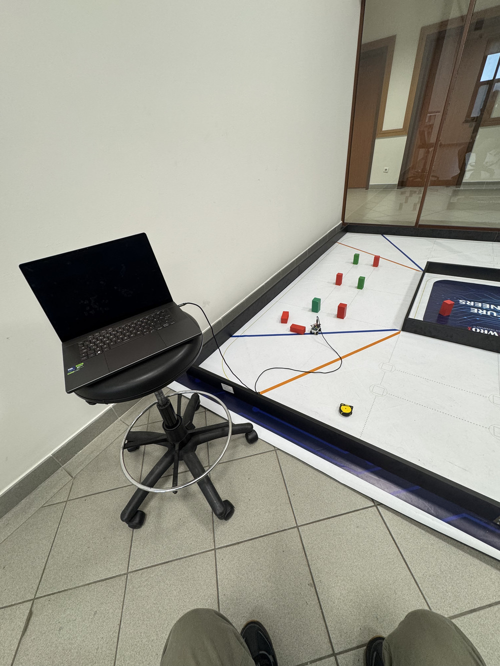
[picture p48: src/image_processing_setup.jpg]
Software Development Setup

<p align="center"><em>Software development and testing environment</em></p>
</td>
</tr>
</table>

## 💻 Programming Environment & Tools

### STM32H747 (Camera Microcontroller)
- **Language**: MicroPython
- **Programming**: Micro USB connection to evaluation board
- **Key Libraries**:
  - `machine` - Hardware control (PWM, GPIO, UART)
  - `pyb` - STM32-specific functions and timers
  - `sensor` - Camera interfacing and image processing

### nRF52832 (Sensor Microcontroller)
- **Language**: Arduino C++
- **Programming**: Micro USB connection to evaluation board
- **Key Libraries**:
  - `Wire.h` - I2C communication for sensors

### Ease of Use Features
We implemented a magnetic USB cable for the main camera microcontroller evaluation board, providing practical advantages for frequent programming and debugging sessions. The magnetic connection allows quick disconnects, prevents port damage from constant plugging, and simplifies the development workflow.

### Build & Deployment Process
1. **STM32H747 (MicroPython)**:
   - Copy `.py` files directly to microcontroller filesystem via the magnetic USB cable or micro USB
   - Automatic execution on startup from `main.py`
   - No compilation required - interpreted execution

2. **nRF52832 (Arduino C++)**:
   - Compile in Arduino IDE with nRF5 board support
   - Upload via micro USB to evaluation board
   - Precompiled binary deployment

## 🚀 Core Software Components

### Main Control Files

| File | Microcontroller | Language | Purpose |
|---|---|---|---|
| [`open.py`](open.py) | STM32H747 | MicroPython | Open Challenge navigation with inner wall following |
| [`obstacle.py`](obstacle.py) | STM32H747 | MicroPython | Obstacle Challenge with color detection and parking |
| [`uart_slave.ino`](uart_slave.ino) | nRF52832 | Arduino C++ | Sensor data acquisition and UART communication |

### Sensor Fusion Architecture

**Data Flow Pipeline**:
```
nRF52832 Sensors ←→  UART  ←→ STM32H747 → Sensor Fusion → Control Decisions
     ↑                            ↑             ↑               ↓
  ToF Left                      Camera     PID Controller   Motor/Servo
  ToF Right                     Vision     State Machine     Actuators
 Encoder Data                  IMU Data
                               ToF Front
```

## 🎯 Navigation Strategies & Algorithms

### Open Challenge Strategy
The Open Challenge requires completing laps by following the inner wall while detecting corners using orange/blue markers.

**Key Algorithm Features**:
- **Initial Direction Detection**: Uses front ToF sensor (<800mm) and camera-based orange/blue detection to determine clockwise/counterclockwise direction
- **Wall Following**: Camera-based black wall detection with PID control
- **Corner Detection**: Orange/blue marker recognition for lap counting
- **IMU Integration**: Gyroscope-based heading maintenance
- **Encoder Odometry**: Precise distance tracking for segment navigation

**State Machine Flow**:
```
Initial Forward → Follow Wall → Turn Corner → Follow Wall (repeat)
      ↑               ↑             ↑             ↑
  ToF + Color     Camera PID    IMU 90° Turn  Continue
  Detection      Wall Tracking                Navigation
```

**Open Challenge Pseudocode**:
```
INITIALIZE sensors, set direction = unknown
WHILE direction == unknown:
    DRIVE forward using IMU guidance
    DETECT orange/blue colors
    IF orange detected first: SET direction = clockwise
    IF blue detected first: SET direction = counterclockwise
    IF front ToF < 800mm: TRANSITION to wall following

WHILE corner_count < 12:
    FOLLOW inner wall using camera PID
    DETECT orange/blue corners
    IF corner detected: INCREMENT corner_count
    IF wall lost and min_distance traveled: EXECUTE 90° turn
    UPDATE odometry and heading

EXECUTE final forward movement
STOP
```

### Obstacle Challenge Strategy  
The Obstacle Challenge involves navigating while respecting traffic signs (red: right avoid, green: left avoid) and performing parallel parking.

**Color-Based Navigation**:
- **Red Detection**: Steer right with optimal offset positioning
- **Green Detection**: Steer left with precise camera alignment  
- **Magenta Detection**: Trigger parking maneuver sequence
- **Obstacle Avoidance**: Shortest-path planning around obstacles

**Advanced Features**:
- **Smooth Following**: Maintains obstacles at consistent pixel positions
- **Memory System**: Remembers last detected color during brief losses
- **Search Patterns**: Progressive search algorithms for lost objects

**State Machine Flow**:
```
Determine Direction → Follow Color → Lost Color → Pass Color → U-Turn → Parking
        ↑                 ↑             ↑            ↑           ↑         ↑
   ToF + Color        Camera PID      Search      Avoidance   180° Turn  Magenta
   Detection          Color Track     Pattern     Maneuver    Maneuver   Detection
```

**Obstacle Challenge Pseudocode**:
```
INITIALIZE sensors
DETERMINE direction using side ToF sensors
EXECUTE initial alignment maneuver

WHILE corner_count < 13:
    NAVIGATE using camera color detection
    IF red detected: FOLLOW with right offset
    IF green detected: FOLLOW with left offset  
    IF color lost: SEARCH pattern
    IF color not found: PASS obstacle maneuver
    DETECT orange/blue corners for lap counting

EXECUTE 180° U-turn maneuver
APPROACH parking zone
DETECT magenta parking marker
EXECUTE parallel parking sequence
STOP
```

### Parking Strategy Analysis
We analyzed all possible parking scenarios after completing 3 laps:

<p align="center">
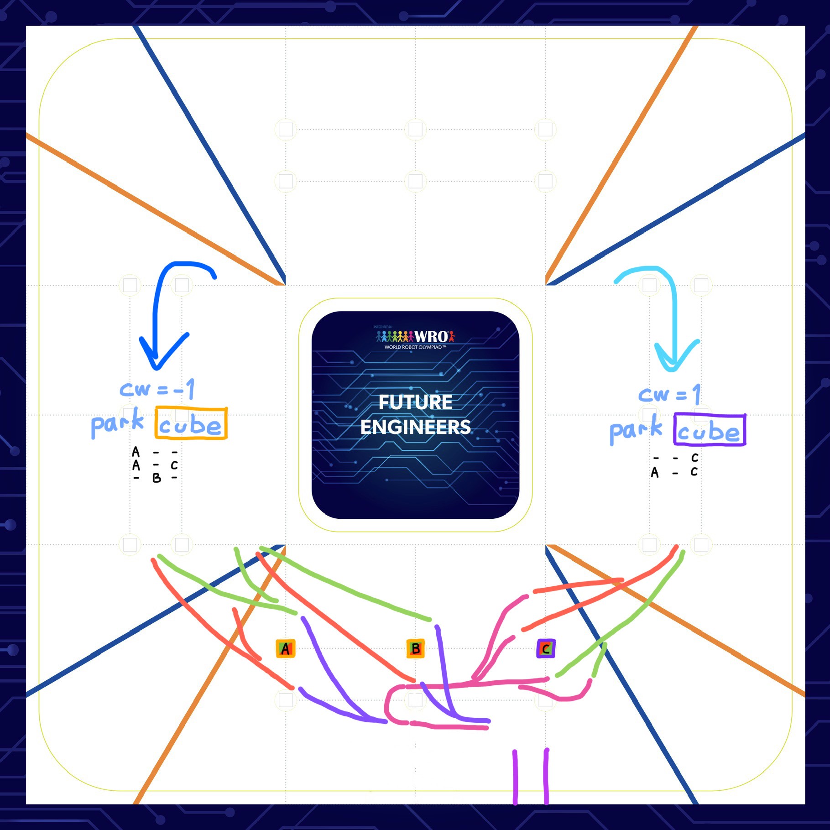
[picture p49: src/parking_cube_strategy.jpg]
Parking with Final Cube
  
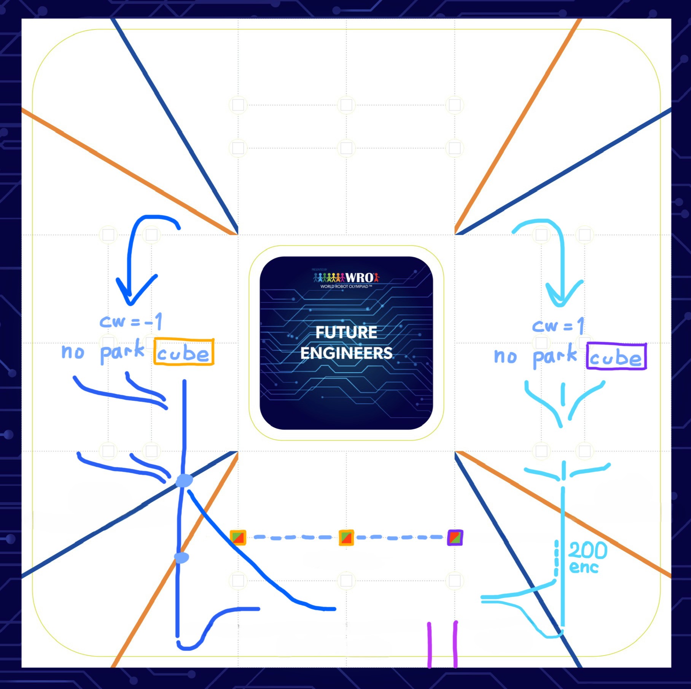
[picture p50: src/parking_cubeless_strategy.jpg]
Parking without Final Cube
  
</p>
<p align="center">
  <em>1) Parking paths including correct final cube avoidance • 2) Direct parking entry without checking final cube</em>
</p>

### Obstacle Combination Strategies
Our algorithm handles all possible obstacle configurations for both directions:

<p align="center">
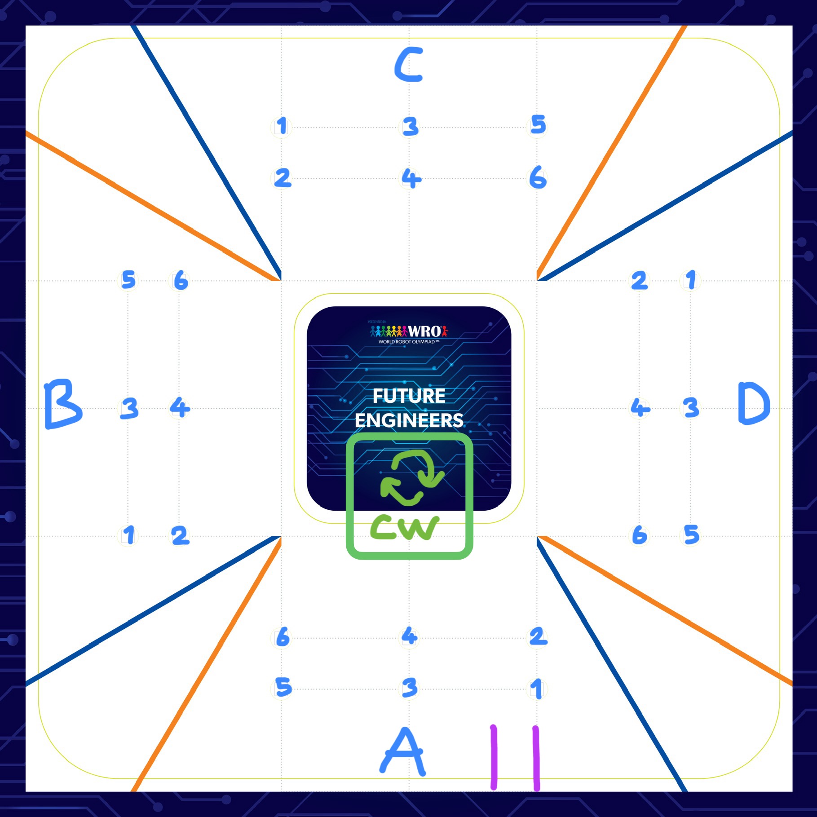
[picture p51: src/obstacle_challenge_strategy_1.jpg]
Clockwise Obstacle Combinations
  
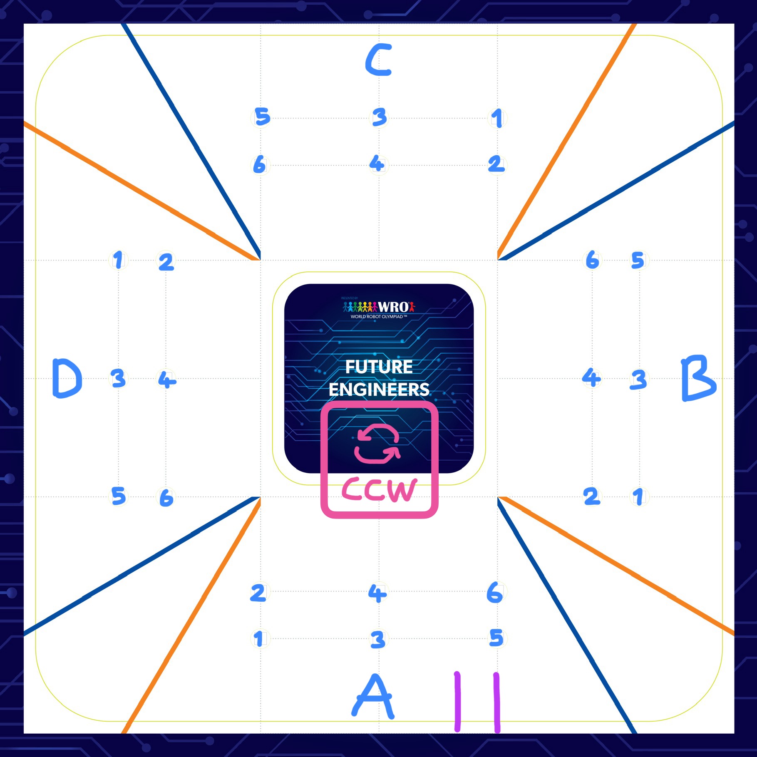
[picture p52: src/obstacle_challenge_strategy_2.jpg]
Counter-Clockwise Obstacle Combinations
  
</p>
<p align="center">
  <em>1) Clockwise navigation with A,B,C,D obstacle combinations 1-6 • 2) Counter-clockwise navigation with A,B,C,D obstacle combinations 1-6</em>
</p>

## 🎨 Computer Vision System

### CIELAB Color Space Selection
We chose the **CIELAB color space** for superior color differentiation under varying lighting conditions compared to traditional RGB or HSV spaces. Our custom `ANTi_threshold_finder.m` MATLAB code helped us determine optimal thresholds for reliable detection through systematic analysis of color distributions under various lighting conditions.

**Color Thresholds (L_min, L_max, A_min, A_max, B_min, B_max)**:
```python
th = {
    "R": [(25, 65, 35, 75, -10, 20)],    # Red obstacle
    "G": [(30, 70, -40, -10, 10, 50)],   # Green obstacle  
    "M": [(40, 80, 60, 90, -20, 30)],    # Magenta parking
    "BK": [(0, 25, -10, 20, -15, 10)],   # Black wall
    "O": [(5, 60, 5, 20, 0, 25)],        # Orange corner
    "B": [(5, 60, 5, 80, -80, -25)]      # Blue corner
}
```

### Vision Processing Pipeline
1. **Image Acquisition**: 320x240 QVGA resolution at 26 FPS
2. **Color Conversion**: RGB565 to CIELAB color space
3. **Blob Detection**: `find_blobs()` with area and pixel thresholds
4. **Target Selection**: Largest blob for reliability
5. **Error Calculation**: Centroid deviation from camera center

<p align="center">
  Example Color Detection
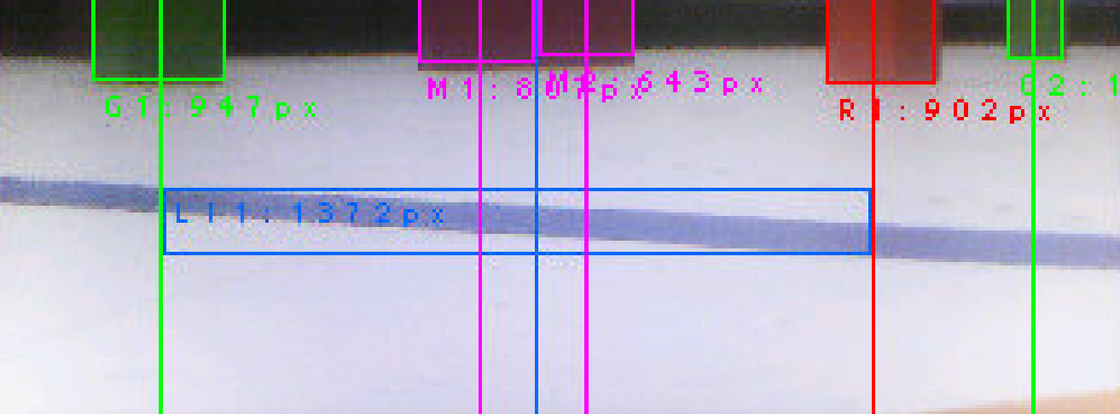
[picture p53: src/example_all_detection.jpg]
Multi-Color Detection
  
</p>

## ⚙️ Control Systems & Sensor Fusion

### PID Control Implementation
**Steering Control**:
```python
# PID gains tuned for smooth navigation
kp, ki, kd = 2.0, 0.001, 1.0
error = cam_error * 0.3 + heading_diff * 0.7
pid_integral = max(-100, min(100, pid_integral + error * ki))
steer = error * kp + pid_integral + (error - last_error) * kd
```

**Code Example from open.py**:
```python
# PID control execution in main loop
pid_integral = max(-100, min(100, pid_integral + error * ki))
steer = error * kp + pid_integral + (error - last_error) * kd
last_error = error
current_speed += min(2, max(-2, target_speed - current_speed))
set_speed(current_speed)
set_steering(240 + steer)
```

**Encoder-Based Positioning Odometry System**:
```python
delta_enc = encoder - last_enc  # Calculate encoder change since last reading
odometry_x += delta_enc * math.cos(math.radians(angle))  # Update X position (left/right)
odometry_y += delta_enc * math.sin(math.radians(angle))  # Update Y position (forward/backward)
```

<p align="center">
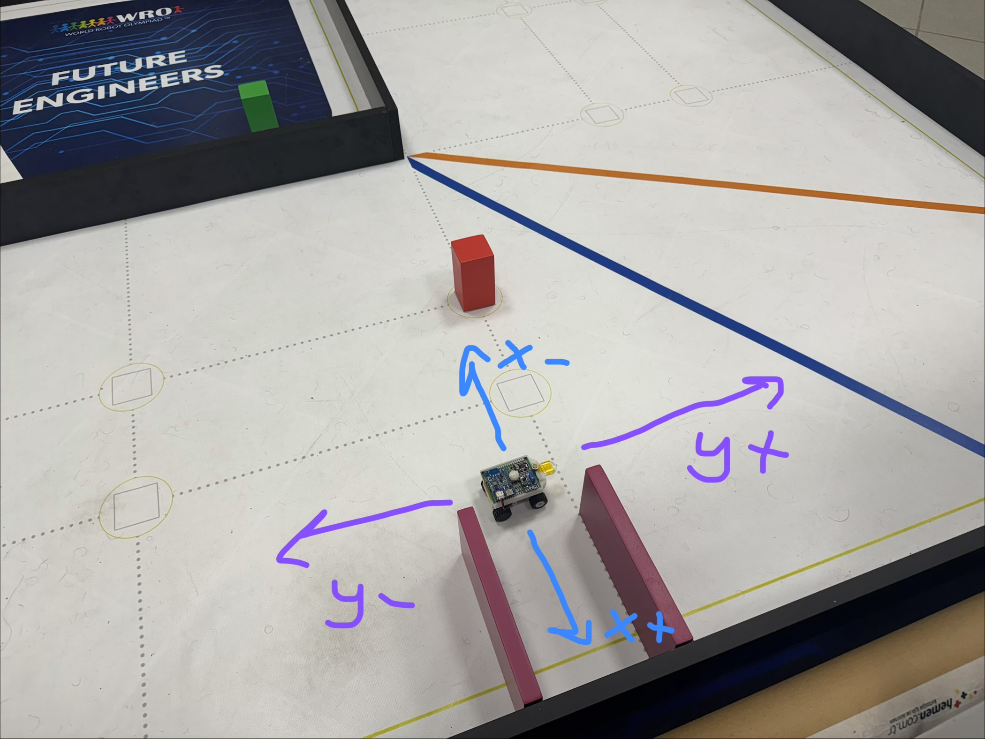
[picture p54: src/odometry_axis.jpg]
Odometry Coordinate System
  
</p>
<p align="center"><em>Coordinate system for encoder-based position tracking (Y+ forward, Y- backward, X- left, X+ right)</em></p>

**Sensor Fusion Strategy**:
- **Primary**: Camera vision for precise positioning
- **Secondary**: IMU gyroscope for heading maintenance  
- **Tertiary**: ToF sensors for parking detection
- **Extra fallback**: Encoder odometry solution tested and ready to implement as backup for distance tracking

### UART Communication Protocol
**Bidirectional Communication Architecture**:

The UART communication between STM32H747 (master) and nRF52832 (slave) implements a robust bidirectional protocol at 115200 baud rate:

**Master (STM32H747) → Slave (nRF52832) Commands**:
- `'r'` - Request all sensor data (left_tof, right_tof, encoder)
- `'t'` - Request left ToF sensor only
- `'u'` - Request right ToF sensor only  
- `'e'` - Request encoder travel distance only
- `'z'` - Reset encoder counter to zero

**Slave Response Formats**:
- **All sensors**: `left_distance,right_distance,encoder_distance\n`
- **Left ToF only**: `left_distance\n`
- **Right ToF only**: `right_distance\n`
- **Encoder only**: `encoder_distance\n`

**Communication Initialization**:
1. **Slave Ready Signal**: nRF52832 sends `0x01` byte when initialized
2. **Master Detection**: STM32H747 waits for ready signal with timeout
3. **Command Cycle**: Continuous request-response pattern during operation

**Data Packet Structure**:
- **Command Byte**: Single character sent from master
- **Response Data**: Comma-separated values or single value from slave
- **Termination**: Newline character (`\n`) marks end of transmission
- **Timeout Handling**: 50ms timeout prevents communication deadlocks

**Multi-Sensor Data Transmission**:
The slave efficiently packages sensor readings into optimized responses:
- **ToF Sensors**: Left and right distance values (0-4000mm range) with bounds checking
- **Encoder Data**: Travel distance in millimeters with float precision (2 decimal places)
- **Data Integrity**: Validation and error handling on both ends

**Hardware Configuration**:
```python
# STM32H747 UART setup
uart = UART(9, baudrate=115200, bits=8, parity=None, stop=1)
```

**Code Example from obstacle.py**:
```python
def fetch_data(command, timeout=50):
    # Send command to slave and parse response
    global tof_left, tof_right, encoder, uart_buffer
    uart.write(command)
    if command in (b'z', b'p'): return True  # No response needed
    start_time = pyb.millis()
    while pyb.elapsed_millis(start_time) < timeout:
        if uart.any():
            uart_buffer += uart.read(uart.any())
            if b'\n' in uart_buffer:
                line, uart_buffer = uart_buffer.split(b'\n', 1)
                if command == b'r' and line.count(b',') == 2:
                    parts = line.split(b',')
                    tof_left = int(parts[0])
                    tof_right = int(parts[1])
                    encoder = float(parts[2])
                    return True
    return False  # Timeout
```

**Code Example from uart_slave.ino**:
```cpp
void processUARTCommand(char command) {
  // Process commands from main vehicle controller
  int left_dist = readDistanceSensor(LEFT_DISTANCE_SENSOR_ADDR);
  int right_dist = readDistanceSensor(RIGHT_DISTANCE_SENSOR_ADDR);
  float travel_distance = encoder_count / PULSES_PER_MILLIMETER;
  
  switch (command) {
    case 'r':  // Return all sensor readings: left_tof,right_tof,encoder
      SERIAL_PORT.print(left_dist); SERIAL_PORT.print(',');
      SERIAL_PORT.print(right_dist); SERIAL_PORT.print(',');
      SERIAL_PORT.println(travel_distance, 2);
      break;
      
    case 't':  // Left sensor only
      SERIAL_PORT.println(left_dist);
      break;
      
    case 'u':  // Right sensor only  
      SERIAL_PORT.println(right_dist);
      break;
      
    case 'e':  // Encoder travel distance
      SERIAL_PORT.println(travel_distance, 2);
      break;
      
    case 'z':  // Reset encoder counter
      encoder_count = 0;
      break;
      
    default:   // Unknown command - ignore
      break;
  }
}
```

**Communication Flow**:
1. **Master Request**: STM32H747 sends single character command
2. **Slave Processing**: nRF52832 reads sensors and formats response
3. **Data Transmission**: Slave sends formatted data with newline termination
4. **Master Parsing**: STM32H747 receives and parses data into global variables
5. **Buffer Management**: Circular buffer handles partial messages and timeouts

This protocol provides flexible sensor data access while maintaining efficient communication bandwidth usage.

## 🛠️ Engineering Challenges & Solutions

### Real-Time Performance Optimization
**Challenge**: MicroPython interpretation overhead affecting control loop frequency

**Solution**:
- Optimized blob detection with restricted ROIs
- Pre-computed color thresholds
- Efficient UART data parsing
- Balanced control loop timing (15-30ms cycles)

### IMU Integration Strategy
**Challenge**: Hardware interrupt-based IMU reading caused significant runtime performance decrease, affecting camera operation and framerate

**Solution**: We implemented a basic IMU calculation approach executed each control loop cycle rather than using interrupts. Despite theoretical advantages of interrupt-based IMU, our solution proved sufficient because:

- **Control Loop Speed**: Each cycle executes rapidly enough for accurate angle integration
- **Camera Priority**: Maintaining high camera framerate was critical for reliable color detection
- **Sufficient Accuracy**: Even with basic integration, our IMU provided perfect angle values for vehicle navigation
- **Performance Validation**: Achieved competition-best times (16s Open, 35s Obstacle) confirming IMU reliability

**10-Second IMU Calibration Routine:**:
```python
# Collect 1000 samples to determine zero offset
calibration_samples = 1000
calibration_sum = 0.0
while calibration_count < calibration_samples:
    gyro_sample = read_gyro()
    calibration_sum += gyro_sample
    calibration_count += 1
gyro_zero_offset = calibration_sum / calibration_count
```

**Implementation**:
```python
# Basic gyro integration each control cycle
gyro = read_gyro() - gyro_zero_offset
angle += gyro * dt
```

This approach allowed us to maintain both high-performance camera operation and accurate IMU readings, demonstrating that sometimes simpler solutions can be more effective in integrated systems.

### 🅿️ Parallel Parking Strategy Optimization

**🚧 Challenge**: Our compact vehicle design (69mm length) required extremely precise parallel parking maneuvers within the tight 1.5× vehicle length parking space (103.5mm)

**💡 Initial Solution**: We designed and implemented a strategic front extension piece that provided crucial benefits:

- **📏 Length Extension**: Added 21mm front piece increased total vehicle length to 90mm
- **Parking Space Optimization**: Parking lot requirement became 90mm × 1.5 = 135mm (13.5cm)
- **Critical Width Design**: The narrow width of the extension piece allowed clearance from parking walls during turning maneuvers
- **🔄 Improved Maneuverability**: Additional space enabled more reliable parking execution

**Multi-Stage Parking Maneuver**:
1. **Approach**: Follow magenta wall with camera guidance
2. **Turn-in**: 80-degree turn outside parking spot
3. **Alignment**: Odometry-based reverse positioning
4. **Reverse**: Controlled backing for final alignment
5. **Straighten**: Final orientation adjustment

> 💡🐜 ***Fun Discovery***: The distinctive front extension piece gave our vehicle a unique appearance that reminded us of an **ANT**'s mandible, perfectly matching our team name and creating a memorable visual identity!
<p align="center">
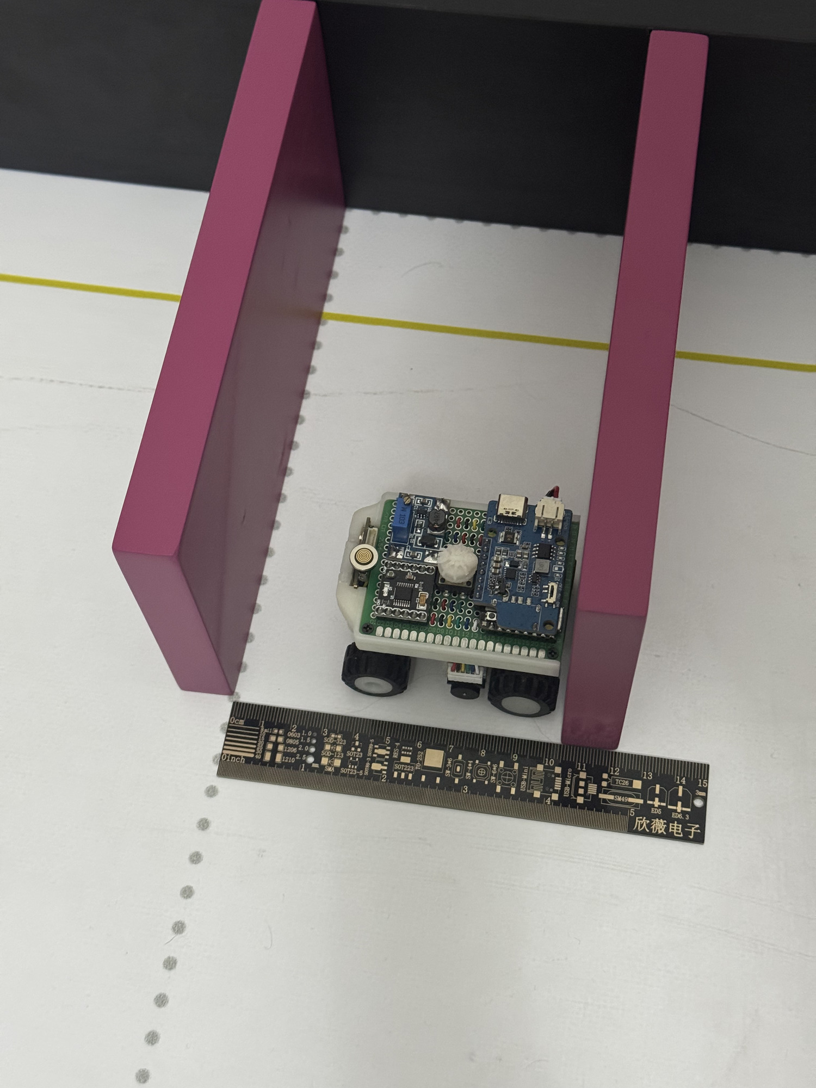
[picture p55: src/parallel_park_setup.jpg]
Original 69mm Vehicle in Parking Lot
  
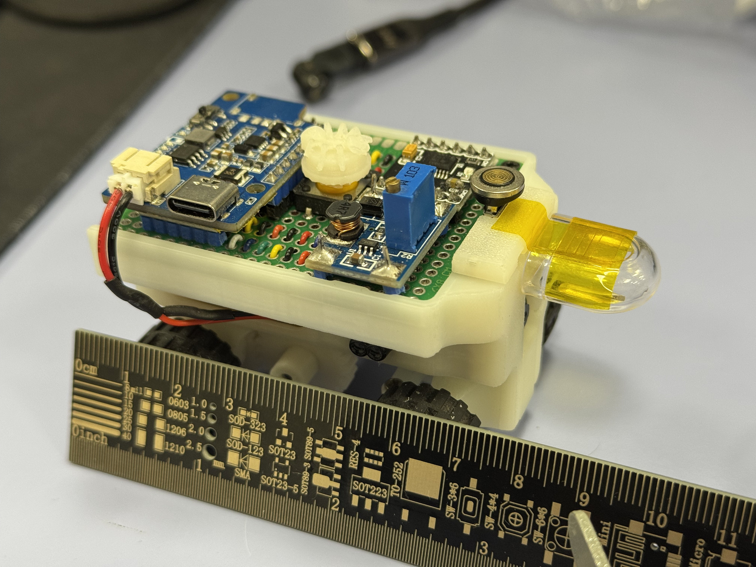
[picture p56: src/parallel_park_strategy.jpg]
90mm Vehicle with Extension
  
</p>
<p align="center">
  <em>1) Original 69mm vehicle in tight parking space • 2) Extended 90mm vehicle with strategic front piece</em>
</p>

**💡 Final Evolution**: After extensive testing, we iterated on the extension design to further enhance safety and performance:

- **📏 Enhanced Length**: Increased extension to 41mm for total vehicle length of 110mm
- **Parking Space Adjustment**: Expanded requirement to 110mm × 1.5 = 165mm
- **Improved Safety Margin**: Greater clearance for multi-turn maneuvers while maintaining higher speeds
- **Design Refinements**: Incorporated competition stickers creating "ANTi" branding and ant-inspired eyes
- **Maneuver Strategy**: Retained multiple-turn parking for optimal speed-safety balance

<p align="center">
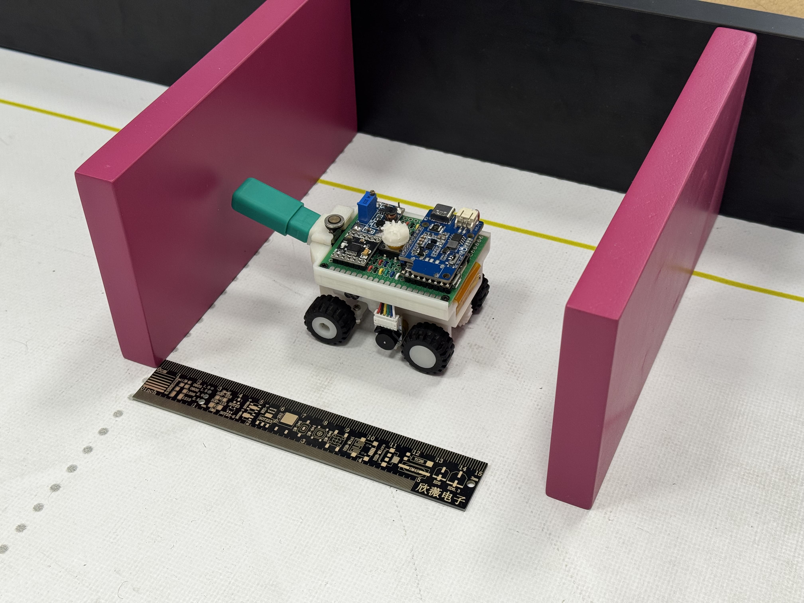
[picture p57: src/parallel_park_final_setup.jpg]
Final 110mm Vehicle in Extended Parking Lot
  
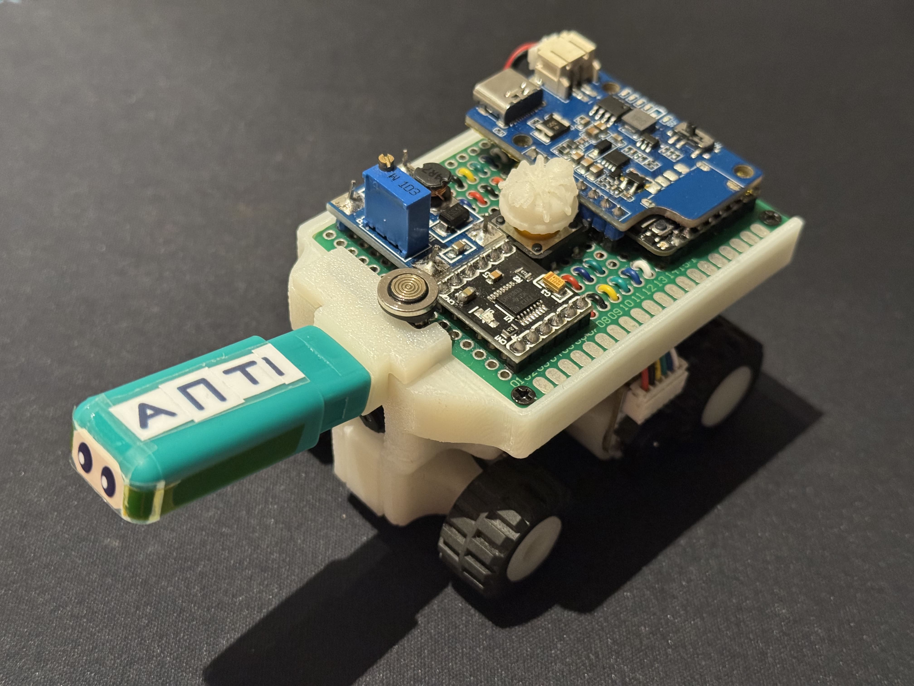
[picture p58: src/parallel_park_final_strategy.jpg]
Final Extension Design Detail
  
</p>
<p align="center">
  <em>1) Final 110mm vehicle in 165mm parking space with measurement verification • 2) Close-up of refined extension with custom branding and visual enhancements</em>
</p>

### Lighting Condition Adaptation

**🌅 Challenge**: Varying competition lighting conditions affecting color detection accuracy

**💡 Solution**:
- 🎨 **CIELAB Color Space** for superior lighting invariance compared to traditional RGB or HSV spaces
- 📊 **MATLAB Analysis** using our custom `ANTi_threshold_finder.m` code for systematic color distribution analysis
- **Extensive Calibration** under multiple lighting conditions including direct sunlight
- ⚙️ **Dynamic Threshold Adjustment** based on ambient light levels
- **Robust Blob Detection Parameters** with optimized area and pixel thresholds

<p align="center">
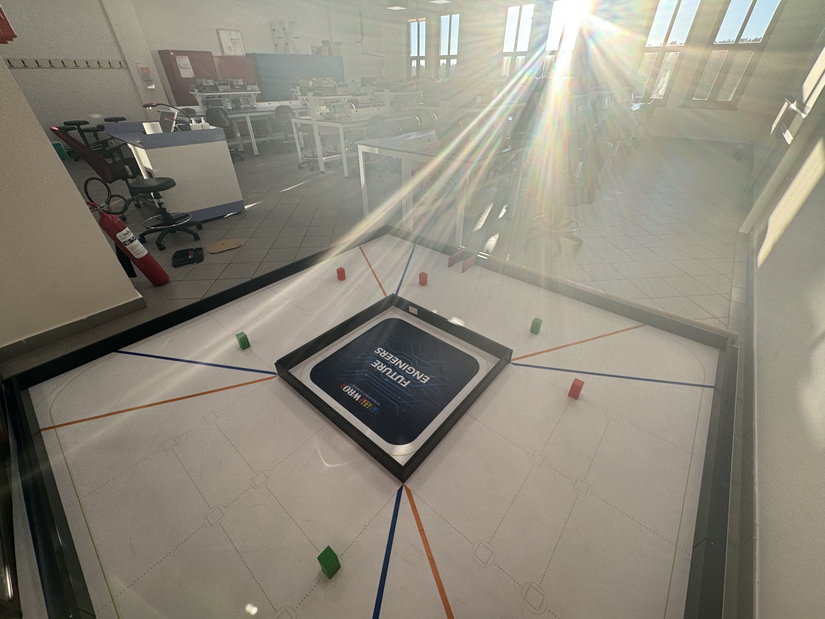
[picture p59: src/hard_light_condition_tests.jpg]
Lighting Condition Tests
  
</p>
<p align="center"><em>Comprehensive testing under challenging lighting conditions including direct sunlight</em></p>

## 📊 Navigation Flow & State Machines

### ⚡ Open Challenge Detailed Strategy
**Initial Phase - Direction Determination**:
1. **Unknown Start**: Begin with direction = 0 (unknown)
2. **Forward Approach**: Drive straight using IMU guidance only
3. **Color Detection**: Simultaneously detect orange or blue markers
4. **Direction Assignment**: First detected color sets direction (orange: CW=1, blue: CCW=-1)
5. **ToF Transition**: Switch to camera guidance when front ToF detects <800mm

**Main Navigation Phase**:
- **Wall Following**: Camera-based black wall tracking with PID control
- **Corner Detection**: Orange/blue markers increment corner count
- **Precise Turns**: 90-degree turns using IMU gyro integration
- **Segment Management**: Encoder-based distance tracking between corners

### 🚦Obstacle Following Approach
Our obstacle navigation implements an advanced following strategy that maintains optimal positioning:

**Core Following Logic**:
- **Consistent Positioning**: Maintain obstacles at specific X pixel positions in camera frame
- **Offset Calculation**: Different offsets for inner (30px) and outer (30px) obstacles based on direction
- **Smooth Tracking**: PID control combines camera error with heading error for smooth combined sensor fusion and vehicle motion
- **Shortest Path**: Algorithm always forms the most direct path around obstacles

**Color-Specific Behavior**:
- **Red Obstacles**: Keep at *CAM_CENTER - offset* (left offset positioning for proper right avoidance)
- **Green Obstacles**: Keep at *CAM_CENTER + offset* (right offset positioning for proper left avoidance)  
- **Adaptive Offsets**: Direction and color dependent offset calculation for universal strategy
- **Sensor Fusion**: Heading IMU sensor combined with camera vision for smooth, stable control approach

**Performance Advantage**: This approach enables both high speed (1.4 m/s operational) and minimal oscillation, creating the smoothest target-driven algorithm in the competition through precise sensor fusion of vision and angle guidance.

## 🧪 Testing & Validation

### Test Suite (`/tests` Directory)
- [`blink.py`](tests/blink.py) - LED and basic I/O verification
- [`camera_test.py`](tests/camera_test.py) - Camera functionality and color detection
- [`imu_test.py`](tests/imu_test.py) - Gyroscope calibration and reading
- [`tof_test.py`](tests/tof_test.py) - Distance sensor validation
- [`button_photo.py`](tests/button_photo.py) - Input device testing

### Simulation Concept
We initially developed a Webots simulation (`ANTi_wro_sim.wbt`) as a universal testing platform. However, due to timeline constraints and the complexity of accurately modeling our custom mechanical systems and sensor behaviors, we converted our development focus directly to physical implementation. The simulation served as a valuable conceptual framework before transitioning to real-world testing.

<p align="center">
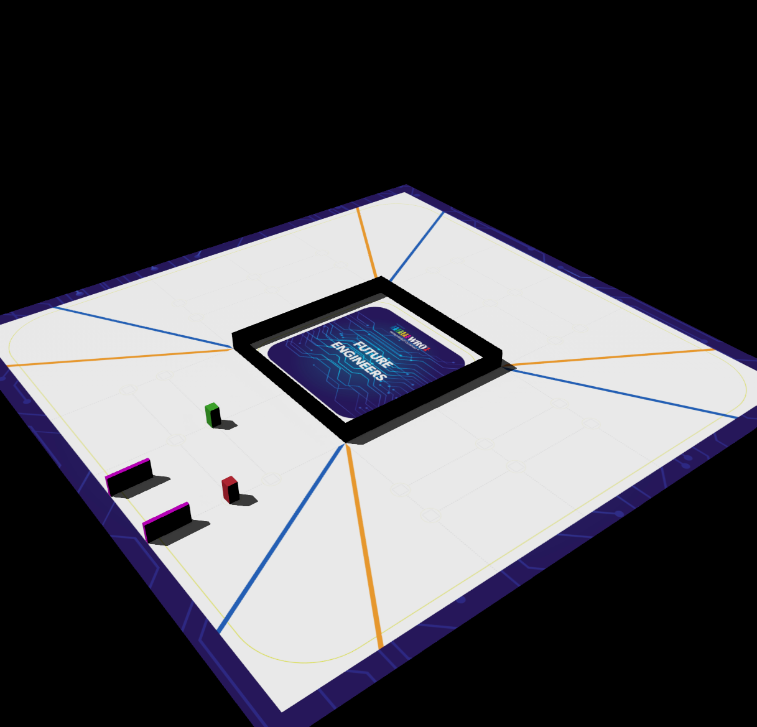
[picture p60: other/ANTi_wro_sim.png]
Webots Simulation Environment
  
</p>
<p align="center"><em>Initial Webots simulation environment used for conceptual development and algorithm testing</em></p>

### 🏆 Performance Validation
- **Open Challenge**: 16 seconds full score - [Watch Performance Video](../video/README.md#competition-performance-videos)
- **Obstacle Challenge**: 35 seconds full score - [Watch Performance Video](../video/README.md#competition-performance-videos)
- **Color Detection**: >95% accuracy under competition lighting
- **Control Response**: <50ms latency from detection to actuation

**Video Documentation**: Full performance demonstrations showcasing our robot's capabilities in both challenges are available in our [Video Documentation](../video/README.md), including:
- 🎯 Autonomous navigation and speed control on dynamic tracks
- 🚦 Traffic sign detection and obstacle avoidance
- 🅿️ Optimal path planning and parallel parking maneuvers
- ⚡ Smooth obstacle following at consistent distances

## 📁 File Structure & Dependencies

### Complete File List
| File | Description |
|---|---|
| [`open.py`](open.py) | Open Challenge main control logic |
| [`obstacle.py`](obstacle.py) | Obstacle Challenge with parking |
| [`uart_slave.ino`](uart_slave.ino) | nRF52832 sensor firmware |
| [`ANTi_wro_sim.wbt`](ANTi_wro_sim.wbt) | Webots simulation file (conceptual reference) |
| [`/tests/`](tests/) | Development and validation test scripts |

### External Dependencies
- **MicroPython Firmware** - STM32H747 compatible version
- **Arduino nRF5 Board Support** - nRF52832 compilation

## 🚀 Deployment Instructions

### STM32H747 Setup (Camera MCU)
1. Connect via magnetic micro USB cable to computer
2. Copy MicroPython files to microcontroller filesystem:
   ```bash
   cp open.py /path/to/stm32/
   cp obstacle.py /path/to/stm32/ 
   ```
3. Files execute automatically on startup from `main.py`

### nRF52832 Setup (Sensor MCU)  
1. Open `uart_slave.ino` in Arduino IDE
2. Select nRF52832 board and proper port
3. Compile and upload via micro USB
4. Verify sensor data over Serial monitor

### System Startup
1. Power on LiPo Rider Plus switch
2. Wait for slave microcontroller ready signal
3. Press tactile start button to begin navigation
4. RGB LED indicates operational status

## ✅ Code Quality & Best Practices

### Software Engineering Principles
- **Modular Design**: Separated vision, control, and sensor modules
- **Comprehensive Documentation**: Inline comments and function descriptions
- **Error Handling**: Robust exception handling with LED status indicators
- **Resource Management**: Efficient memory usage and power management

### Performance Optimizations
- **Minimal Memory Allocation**: Pre-allocated buffers and fixed-size arrays
- **Efficient Algorithms**: Optimized blob detection and PID computations
- **Timing Control**: Balanced control loop frequencies for stability
- **Sensor Fusion**: Intelligent data weighting and validation

## 🔮 Future Improvements

### Planned Enhancements
- **Machine Learning Integration**: Lightweight neural network for improved color classification if traditional thresholding proves insufficient
- **Dynamic Path Planning**: A* algorithm implementation for optimal obstacle avoidance
- **Adaptive Control**: Self-tuning PID parameters based on performance metrics
- **Extended Simulation**: Enhanced Webots model for algorithm validation

### Research Directions
- **Wireless Communication**: Real-time performance monitoring only for debugging process
- **Advanced Sensor Fusion**: Kalman filtering for improved position estimation
- **Energy Optimization**: Dynamic power management based on task requirements
- **Custom Modular Sensor System**: Easy reconfiguration with existing sockets

We challenged ourselves beyond the traditional competition rules to further develop our engineering knowledge across all aspects of the project, and we encourage future teams to continue this philosophy of pushing boundaries while maintaining comprehensive documentation.

---

This comprehensive software documentation provides complete transparency into our algorithm design, implementation details, and engineering decision-making process. All code is structured for easy understanding and replication, meeting WRO Future Engineers competition requirements for detailed technical documentation.

For hardware implementation: [Schemes Documentation](../schemes/README.md)  
For mechanical design: [Models Documentation](../models/README.md)  
For performance videos: [Video Documentation](../video/README.md)  
For additional resources: [Other Documentation](../other/README.md)

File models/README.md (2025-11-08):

# Models Documentation

This folder contains the complete 3D CAD models and manufacturing files for Team ANTi's WRO 2025 Future Engineers robot. All mechanical components were custom-designed and manufactured in-house to achieve our goal of creating the world's smallest autonomous vehicle while maintaining optimal performance. This documentation was last updated on **Saturday, November 08, 2025, at 08:13 AM +03**.

## 🎯 Mechanical Design Philosophy

Our design philosophy centered around **minimalism without compromise** - achieving the smallest possible footprint while ensuring robust mechanical performance. The entire chassis measures just **69mm (L) x 53mm (W) x 57mm (H)** with a total weight of **~130g**, making it the smallest autonomous vehicle in WRO Future Engineers category.

<p align="center">
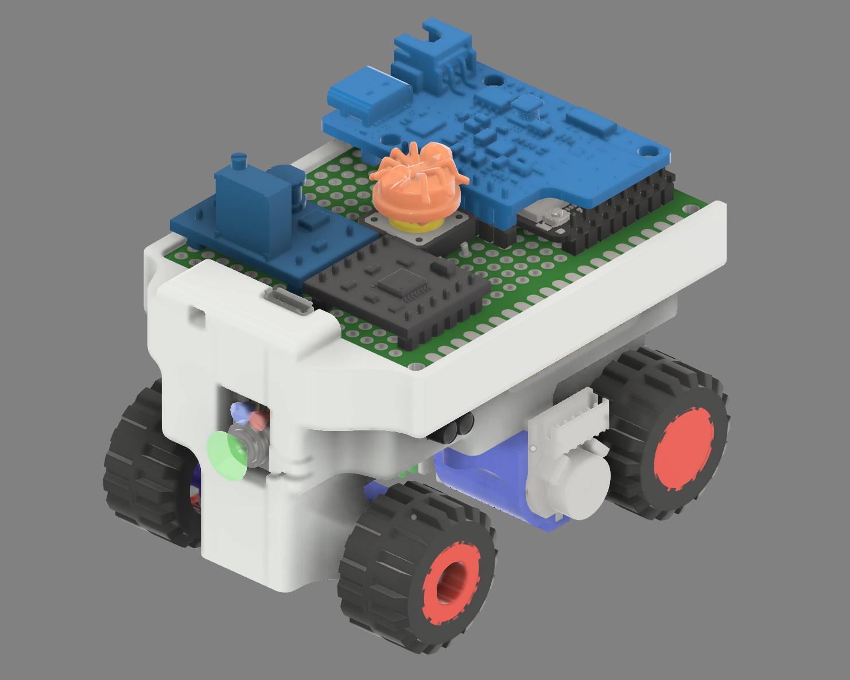
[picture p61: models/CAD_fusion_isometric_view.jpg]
CAD Isometric View
  
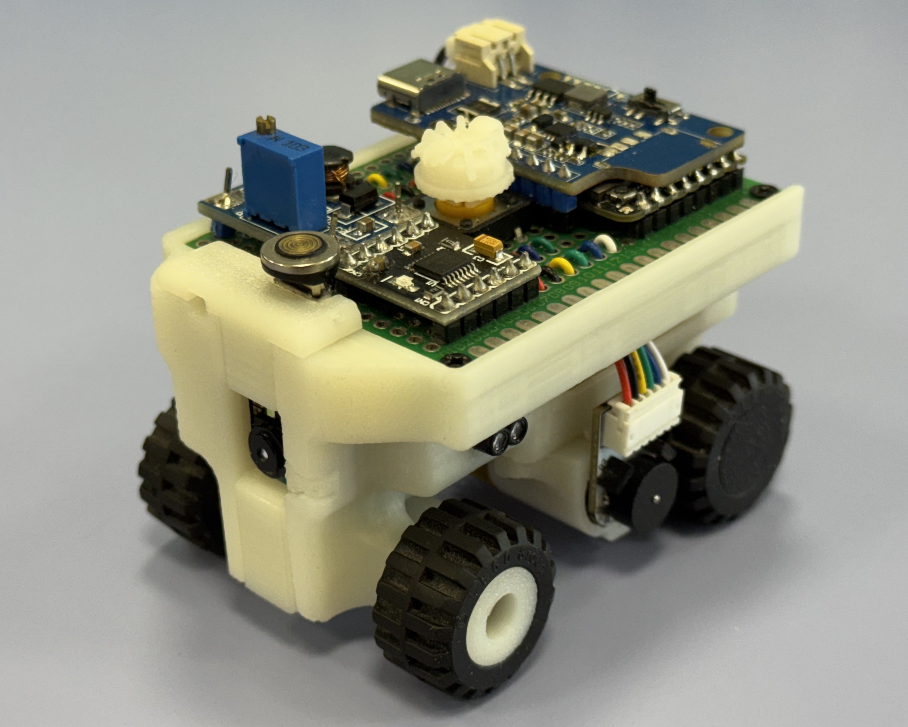
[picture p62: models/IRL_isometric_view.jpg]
Real Life Isometric View
  
</p>
<p align="center">
  <em>Direct comparison: 1) CAD design visualization vs 2) physical implementation from identical isometric perspectives</em>
</p>

## ⚙️ Core Mechanical Systems

### 🔄 Custom Ackermann Steering Geometry
The steering system implements true Ackermann principles where each wheel points toward a common center point during turns, minimizing tire scrub and maximizing stability.

<p align="center">
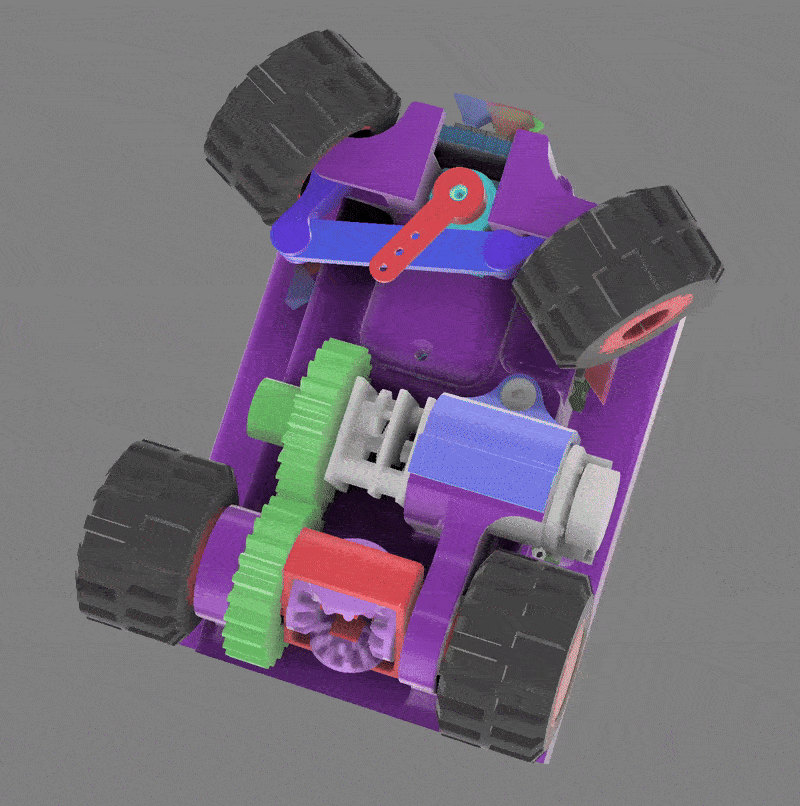
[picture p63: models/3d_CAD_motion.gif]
Ackermann Steering Simulation
  
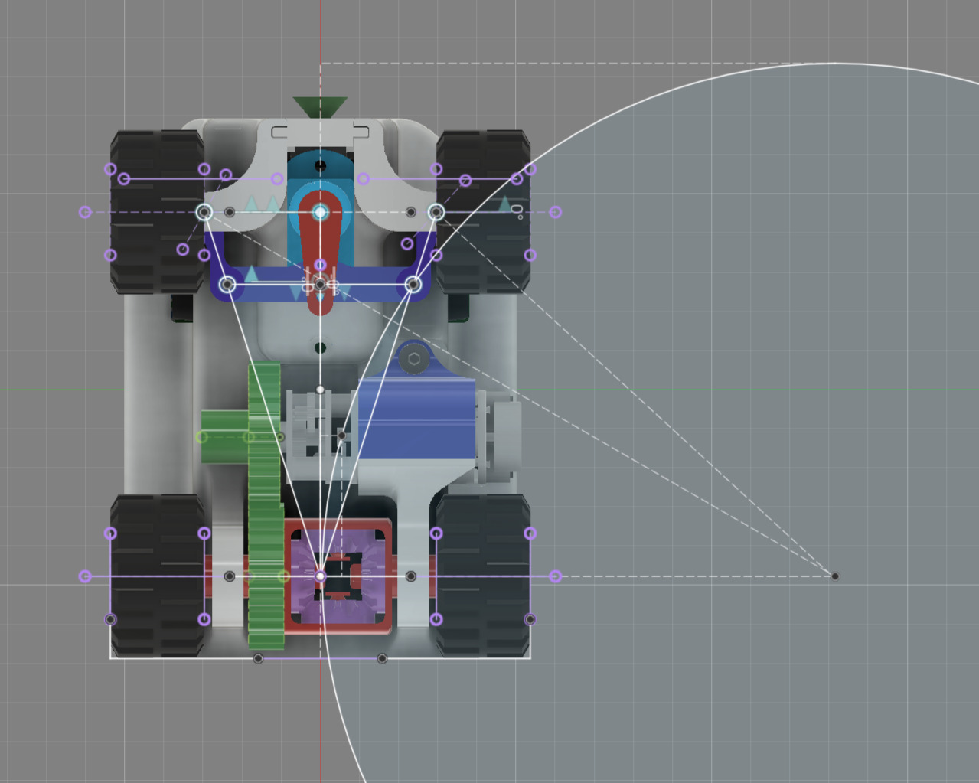
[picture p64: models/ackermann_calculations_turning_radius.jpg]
Ackermann Geometry Calculations
  
</p>
<p align="center">
  <em>1) Real-time CAD simulation demonstrating steering mechanism operation • 2) Engineering calculations showing Ackermann geometry and optimal turning radius</em><br>
  <em>Higher quality video: <a href="../video/3d_CAD_motion.mp4">3d_CAD_motion.mp4</a></em>
</p>

**Engineering Progress & Refinement:**
- **Initial Approach**: Print-in-place Ackermann steering with integrated moving parts
- **Performance Finding**: Initial excellent tolerance degraded after extensive testing causing wheel wiggle
- **Final Solution**: Multi-component steering with 4 M2 screws and 2 M2 lock nuts ensuring permanent precision
- **True Ackermann Geometry**: Each wheel points toward common center point during turns for minimal tire scrub
- **Optimized Wheel Rotation**: -50° (left) to +32° (right) providing optimal turning radius for 3m×3m track

### 🔧 4-Gear Mechanical Differential
Our custom differential ensures smooth power distribution to both rear wheels during turns, preventing wheel slip and maintaining traction during complex maneuvers.

<p align="center">
  <table align="center">
    <tr>
      <td align="center">
        Physical Differential Test
      </td>
      <td align="center">
        CAD Differential View 1<br>
        CAD Differential View 2
      </td>
    </tr>
  </table>
</p>
<p align="center">
  <em>1) Physical differential test demonstrating independent wheel rotation • 2) CAD views showing 4-gear differential assembly from multiple angles</em><br>
  <em>Higher quality video: <a href="../video/differential_test.mp4">differential_test.mp4</a></em>
</p>

**Gear System Specifications:**
- **Spur Gear Reduction**: 25-tooth and 26-tooth providing optimized 26:25 reduction ratio
- **Bevel Gear Differential**: 12-tooth gears enabling smooth power distribution during turns
- **Precision Manufacturing**: 100% infill for maximum strength and durability
- **Efficiency Optimization**: Minimal power loss through precisely calculated gear meshing

### 🏗️ Chassis and Structural Design
The main chassis integrates all mechanical and electronic systems while maintaining structural integrity and achieving minimal weight through strategic design.

<p align="center">
  <table align="center">
    <tr>
      <td align="center">
        Chassis Development
      </td>
      <td align="center">
        CAD base View 1<br>
        CAD base View 2
      </td>
    </tr>
  </table>
</p>
<p align="center">
  <em>1) Extensive chassis design evolution through multiple iterations • 2) CAD views showing main chassis structure from different perspectives</em>
</p>

**Structural Engineering Elements:**
- **Integrated Component Mounting System**: Precision slots and holders for pertinax boards, servo, motor, and battery
- **Optimized Weight Distribution**: Strategic mass placement ensuring stable navigation and quick response
- **Bearing Integration**: Four precision bearings (one per wheel) for smooth rotation with minimal friction
- **Access and Maintenance Design**: Strategic openings enabling easy component replacement and field adjustments

## 🏭 Manufacturing Process & Engineering Solutions

### 🖨️ 3D Printing Equipment & Material Strategy
We conducted extensive testing across multiple printing technologies in our university makerspace to achieve optimal results.

**CAD & Slicing Software Integration**:
- **Design Platform**: ***Autodesk Fusion*** for comprehensive 3D modeling, simulation, and engineering analysis
- **Slicing Software**: ***Creality Print 6.3*** for optimized print preparation and manufacturing parameter management
- **Workflow Integration**: Seamless transition from CAD design to manufacturing-ready 3MF files

<p align="center">
  3D Printing Setup
</p>
<p align="center">
  <em>Ender 3v3 printer in operation - our primary manufacturing equipment</em>
</p>

**Printing Equipment Evaluation:**
| Printer | Technology | Primary Usage | Materials Tested | Key Findings |
|---|---|---|---|---|
| **Ender 3v3** | FDM (Fused Deposition Modeling) | Final production | Hyper ABS, ABS+ | **Optimal Choice** - Reliable performance with ABS materials |
| **Zaxe Z3S** | FDM (Fused Deposition Modeling) | Development phase | PLA, ABS | Excellent precision and reliability |
| **Bambu Lab A1** | FDM (Fused Deposition Modeling) | Rapid prototyping | PLA | Exceptional speed for design iterations |
| **Markforged Mark Two** | CFR (Continuous Fiber Reinforcement) | Advanced testing | Onyx (Nylon+CF) | Limited by proprietary Eiger software constraints |
| **Formlabs Form 3B+/3+** | SLA (Stereolithography) | Detail testing | SLA Resins | Superior detail but insufficient impact strength and resin alternatives|

### 🛠️ Comprehensive Material Selection Process
**Final Material: Hyper ABS from Creality**  
Selected for superior layer adhesion, impact resistance, and thermal stability required for competition conditions.

**Material Testing Results & Rationale:**
- ✅ **FDM - Hyper ABS (Production Choice)**: Optimal strength-to-weight ratio, excellent layer bonding, competition-ready durability
- ✅ **FDM - ABS+ (Development Phase)**: Good performance used during national tournament
- ❌ **FDM - PLA**: Adequate for initial prototyping but insufficient impact resistance for competition use
- ❌ **FDM - PETG**: Challenging dimensional accuracy and stringing issues affecting gear performance
- ❌ **SLA - Resin**: Exceptional detail resolution but too brittle for structural components under stress, plus limited availability for reproduction
- ❌ **CFR - Onyx (Nylon+CF)**: Exceptional strength but limited by proprietary software preventing custom support optimization and challenging reproducibility

**Selection Philosophy**: Chosen materials prioritize **accessibility** and **reproducibility** alongside performance, ensuring other teams can easily replicate our design using commonly available FDM technology rather than specialized industrial equipment.

**Technology Overview:**
- **FDM (Fused Deposition Modeling)**: Material extrusion through heated nozzle, ideal for functional parts
- **SLA (Stereolithography)**: UV laser curing liquid resin, excellent for high-detail prototypes  
- **CFR (Continuous Fiber Reinforcement)**: Composite printing with continuous fiber strands for maximum strength

### 🔥 Engineering Challenge: ABS Printing Without Dedicated Enclosure
**Problem Identification**: Printing ABS material on Ender 3v3 without dedicated heated enclosure caused warping and layer separation issues.

**Innovative Solution**: Developed room-scale thermal management system using the entire workspace as a controlled environment.

**Thermal Management Process:**
1. **Environmental Pre-conditioning**: Maintain ambient temperature at 28-32°C throughout printing process
2. **Stable Printing Execution**: Complete ABS printing with consistent thermal environment minimizing thermal gradients
3. **Controlled Gradual Cooling**: Allow natural cooling with minimal ventilation to prevent rapid temperature changes
4. **Stabilized Part Extraction**: Remove finished components only after complete thermal stabilization
5. **Process Repeatability**: Continue manufacturing sequence using identical thermal management for consistency

**Optimized Printing Parameters:**
- **Layer Resolution**: 0.08mm–0.1mm for dimensional accuracy and surface finish
- **Infill Strategy**: 30-40% for structural chassis components, 100% for gears and high-stress elements
- **Temperature Control**: Nozzle 250-260°C, Bed 80-85°C for optimal layer adhesion
- **Nozzle Configuration**: 0.4mm standard nozzle (available equipment)
- **Support Strategy**: Tree supports preferred for optimal material usage and clean removal

**Advanced Speed Settings:**
- **Print Speeds**: Outer wall 200 mm/s, Inner walls 300 mm/s, Sparse infill 200 mm/s
- **Specialized Settings**: Top surface 200 mm/s, Gap infill 200 mm/s, Support 150 mm/s
- **Quality Optimization**: Support interface 80 mm/s, First layer 60 mm/s
- **Travel & Overhangs**: Travel speed 500 mm/s, Overhang reduction 30-20-10%
- **Bridge Control**: External bridges 25 mm/s, Internal bridges 160 mm/s

### 📁 3MF File Format Advantage
**Why 3MF for Maximum Reproducibility:**
- **Universal Compatibility**: Works across all printer brands and slicing software, unlike machine-specific G-code
- **Complete Scene Preservation**: All print settings, orientations, and arrangements embedded
- **Advanced Feature Support**: Custom support placements, support settings, and manual modifications preserved
- **Color & Material Information**: Visual specifications maintained for consistent results
- **Exact Alignment**: Bed positioning and part orientation preserved for identical outcomes
- **One-Click Manufacturing**: Direct import with all manufacturing parameters intact for perfect reproduction

## 🧩 Comprehensive Assembly Guide

### 📋 Detailed Step-by-Step Assembly Process

<p align="center">
  Assembly Process
</p>
<p align="center">
  <em>Intermediate assembly stage showing mechanical systems integration and component relationships</em>
</p>

**Phase 1: Drive Train Assembly & Power Transmission**
1. **Differential System Installation**: Precision alignment of 4-gear mechanism ensuring smooth power transfer
2. **Motor Integration**: Secure mounting of 1500 RPM N20 motor with custom enclosure using M2 hardware
3. **Gear Meshing Verification**: Ensure proper engagement of 25T and 26T spur gears with optimal backlash

**Phase 2: Steering System Integration & Control**
1. **Ackermann Mechanism Assembly**: Install steering arms and linkage with 4 M2 screws and 2 M2 lock nuts
2. **Servo Integration**: Connect Feetech FS0307 servo to steering mechanism with precise alignment
3. **Front Wheel System**: Install bearings and front rims ensuring smooth rotation and minimal play

**Phase 3: Chassis Completion & System Integration**
1. **Electronic Platform Mounting**: Secure pertinax boards with all electronic systems in designated slots
2. **Power System Installation**: Mount Power-Xtra LiPo battery in optimized weight distribution position
3. **Final Mechanical Validation**: Comprehensive check of all systems for optimal performance and reliability

## 🔄 Component Development & Engineering Iteration

<p align="center">
  Component Development
</p>
<p align="center">
  <em>Comprehensive component evolution demonstrating our iterative design process across gear systems, steering mechanisms, and structural elements</em>
</p>

**Development Scope & Engineering Iterations:**
- **Gear System Evolution**: Multiple generations optimizing tooth profile, meshing efficiency, and strength
- **Steering Mechanism Refinement**: Various iterations achieving precision control with minimal mechanical play
- **Structural Component Optimization**: Chassis, rims, and mounting systems refined through performance testing
- **Integration Validation**: Continuous testing ensuring component compatibility and system reliability
- **Print-in-Place Validation**: Manufacturing process refinement for optimal production quality

## 🎯 Advanced Wheel & Tire System Engineering

### 🔍 Comprehensive Tire Analysis & Performance-Based Selection

<p align="center">
  LEGO Wheel Analysis
  Silicone Tire Testing
</p>
<p align="center">
  <em>1) Detailed LEGO wheel variant analysis showing design differences • 2) Silicone vs LEGO tire performance comparison testing</em>
</p>

**Technical Tire Comparison & Engineering Analysis:**

| Engineering Aspect | LEGO 87697 | Custom Silicone Tires |
|---|---|---|
| **Material Composition** | SEBS (Styrene-Ethylene-Butylene-Styrene) | Custom silicone compound formulation |
| **Theoretical Traction** | Good predictable performance | Higher theoretical coefficient |
| **Actual Performance** | Optimal for our weight class | Similar results despite theoretical advantage |
| **Design Compatibility** | Perfect fit with custom rims | Required significant rim redesign |
| **Manufacturing Consistency** | Excellent quality control | Variable performance between batches |
| **Weight Impact** | Minimal additional mass | Slightly increased rotational mass due to a larger inner rim with more filling, necessary for better stretching of the silicone tire |

**Final Engineering Selection: LEGO 87697**
- **Optimal Dimensions**: 21mm diameter × 12mm width fitting our size constraints
- **Key Design Feature**: Circumferential center ridge providing stability and predictable handling
- **Performance Characteristics**: Consistent traction with minimal rolling resistance
- **Reliability Assurance**: Proven durability under extended competition conditions

### 🎯 Performance Analysis: Why Theory Didn't Match Reality

<div align="center">
<table>
<tr>
<td><strong>🏋️ Weight Dynamics</strong><br>130g total weight changes traction physics</td>
<td><strong>⚡ Speed Factors</strong><br>1.4 m/s momentum dominates cornering</td>
</tr>
<tr>
<td><strong>🎯 Precision Engineering</strong><br>Near-zero mechanical play in systems</td>
<td><strong>📊 Test Results</strong><br>Identical lap times with both tires</td>
</tr>
</table>
</div>

**Ultra-Lightweight Physics Revolution:**
- **Mass Revolution**: At 130g, traditional tire traction models don't apply
- **Center of Gravity Mastery**: Extremely low CG reduces dependency on tire grip
- **Weight Distribution Science**: Strategic mass placement provides inherent stability

**High-Speed Momentum Dominance:**
- **Physics Reality**: At 1.4 m/s operational speed, momentum overpowers traction benefits
- **Cornering Truth**: Sharp turns rely on precise steering, not tire compound
- **Performance Data**: Both tires demonstrated identical competition performance

**Precision Engineering Advantage:**
- **Zero-Play Systems**: Our mechanical design eliminates steering and drive train slack
- **Predictable Response**: Vehicle handles identically regardless of tire material
- **Algorithm Optimization**: Navigation tuned for positional accuracy over traction dependence

**The Engineering Conclusion:**
While silicone promised higher friction coefficients, our ultra-lightweight, high-precision platform operating at speed revealed that traditional tire performance metrics become secondary. The combination of minimal mass, optimized dynamics, and precision control systems created a scenario where both options performed identically in real-world testing, making consistency and compatibility the deciding factors.

## 📊 Engineering Calculations & Performance Validation

**Motor & Drive Train Engineering Analysis:**
- **Motor Specification**: 1500 RPM N20 DC motor with integrated Hall effect magnetic quadrature encoder
- **Gear Reduction System**: 26:25 ratio through custom spur gear design providing optimal torque-speed balance
- **Wheel RPM Calculation**: 1560 RPM derived through:
    - Wheel RPM = Motor RPM × Gear Ratio = 1500 × (26/25) = 1560 RPM
- **Theoretical Maximum Speed**: 1.72 m/s calculated through:
    - Wheel radius = 21mm / 2 = 10.5mm = 0.0105m
    - Speed = (2 × π × wheel radius) × (Wheel RPM / 60)
    - Speed = (2 × π × 0.0105) × (1560 / 60) ≈ 1.72 m/s
- **Operational Speed Selection**: 1.4 m/s via PWM control providing optimal stability and control response
- **Speed Optimization**: Based on comprehensive calculations comparing wheel/tire sizes and motor speeds for the 3m × 3m game field. Development comparisons available at [motor_speed_calculations.jpg](../other/motor_speed_calculations.jpg)

**Structural & Performance Engineering Validation:**
- **Motor Torque Analysis**: ~0.25 Nm at 6V providing sufficient force for 130g vehicle mass and acceleration requirements
- **Bearing System Design**: Optimized for minimal friction, long-term reliability, and precise wheel alignment
- **Steering Load Calculations**: Ackermann mechanism perfectly matched to servo torque capabilities and response requirements
- **Impact Resistance Validation**: Comprehensive testing under competition conditions confirming structural integrity

## 📁 Complete Manufacturing File Repository

### 🎯 Comprehensive 3D Printing Files & Assembly Specifications
*All files provided in **3MF format** for maximum reproducibility across different printers and slicers.*<br>
*Quantities listed are for one complete vehicle assembly*

| Component | File | Quantity | CAD Preview | Description |
|---|---|---|---|---|
| **Main Chassis** | [`design_base.3mf`](design_base.3mf) | 1 |  | Primary structure with integrated mounting system |
| **4-Gear Differential** | [`design_4_gear_mini_differential.3mf`](design_4_gear_mini_differential.3mf) | 1 |  | Complete differential assembly with 4-gear mechanism and gear slots|
| **Front Rim** | [`design_front_rim_bearing.3mf`](design_front_rim_bearing.3mf) | 2 |  | Front wheel rims with integrated bearing seats (left/right) |
| **Steering Arm** | [`design_steering_arm.3mf`](design_steering_arm.3mf) | 2 |  | Ackermann steering arms (left/right) |
| **Steering Linkage** | [`design_steering_linkage.3mf`](design_steering_linkage.3mf) | 1 |  | Steering connection mechanism |
| **25T Spur Gear** | [`design_spur_25_gear.3mf`](design_spur_25_gear.3mf) | 1 |  | 25-tooth torque transmission gear |
| **26T Spur Gear** | [`design_spur_26_gear.3mf`](design_spur_26_gear.3mf) | 1 |  | 26-tooth motor output gear |
| **12T Bevel Gear** | [`design_bevel_12_gear.3mf`](design_bevel_12_gear.3mf) | 4 |  | Differential bevel gears (4 required for full assembly) |
| **Motor Lid** | [`design_motor_lid.3mf`](design_motor_lid.3mf) | 1 |  | N20 motor mounting enclosure |
| **Long Rear Rim** | [`design_back_rim_long.3mf`](design_back_rim_long.3mf) | 1 |  | Extended for right side, connecting farther from the gear |
| **Short Rear Rim** | [`design_back_rim_short.3mf`](design_back_rim_short.3mf) | 1 |  | Shorter for left side, connecting closer to the gear |
| **Front Top Cover** | [`design_front_top_cover.3mf`](design_front_top_cover.3mf) | 1 |  | Electronics protection cover |
| **Front Bottom Cover** | [`design_front_bottom_cover.3mf`](design_front_bottom_cover.3mf) | 1 |  | Underbody protection |
| **Button Cap** | [`design_button_cap.3mf`](design_button_cap.3mf) | 1 |  | Start button interface |

## 🚀 Engineering Design & Development Process

### 🔄 Comprehensive Iterative Engineering Approach

1. **Conceptual Design & Requirements Analysis**
   - Comprehensive size constraint analysis and optimization
   - True Ackermann steering geometry implementation and validation
   - Strategic component integration planning and spatial optimization

2. **Precision CAD Modeling & Engineering Simulation**
   - Detailed modeling in ***Autodesk Fusion*** with manufacturing considerations
   - Motion simulation and validation for steering and drive train systems

3. **Prototyping & Performance Optimization**
   - Multiple iterations for mechanical tolerance refinement and optimization
   - Comprehensive material testing across various options and conditions
   - Print-in-place component validation and manufacturing process refinement

4. **Production Engineering & System Validation**
   - Optimized printing parameters implementation for production quality
   - Comprehensive assembly procedure development and documentation
   - Competition condition performance testing and validation

## ✅ Engineering Validation & Testing Protocols

### 🧪 Mechanical System Verification & Performance Testing

- **Differential Operation Validation**: Comprehensive testing of smooth torque distribution under various load conditions
- **Steering Geometry Confirmation**: Physical validation of true Ackermann principles in operational implementation
- **Structural Integrity Assessment**: Testing under various surface irregularities to confirm reliability, focusing on the effects of small bumps on a lightweight vehicle.
- **Bearing System Performance**: Long-term testing confirming smooth operation, minimal friction, and reliability

### 🏆 Competition Readiness & Reliability Engineering

- **Regulation Compliance Verification**: Comprehensive adherence to WRO vehicle specifications including 300x200mm maximum dimensions, 1.5kg maximum weight, 4-wheel design with one driving axle and one steering actuator
- **Operational Reliability Demonstration**: Extended testing showing consistent performance under competition pressure
- **Maintenance & Service Protocols**: Established procedures for competition-time adjustments and repairs
- **Backup System Preparation**: Redundant components and systems prepared for competition requirements

---

This comprehensive mechanical documentation provides complete transparency into our design process, manufacturing methods, validation procedures, and engineering decision-making. Every aspect of our mechanical system has been optimized for the unique challenges of autonomous navigation in the WRO 2025 Future Engineers category, enabling exact duplication while demonstrating engineering excellence through detailed component specifications, assembly instructions, performance data, and real-world validation.

For electrical systems documentation: [Schemes Documentation](../schemes/README.md)  
For software implementation and algorithms: [Software Documentation](../src/README.md)  
For performance demonstrations: [Video Documentation](../video/README.md)  
For additional resources and photos: [Other Documentation](../other/README.md)

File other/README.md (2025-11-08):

# Other Resources

This folder contains supplementary materials for Team ANTi's WRO 2025 Future Engineers robot, including component images, technical documentation, development photos, and design resources. This documentation was last updated on **Saturday, November 08, 2025, at 08:23 AM +03**.

## Resource Categories

### Electronic Components
| Component | Image | Description |
|---|---|---|
| STM32H747 | Camera Microcontroller | Dual-core camera microcontroller |
| nRF52832 | Sensor Microcontroller | Sensor microcontroller for sensor computations |
| GC2145 Camera | Camera | 2MP CMOS camera with 80° view angle |
| VL53L1X ToF | ToF Sensor | ToF sensor with 400cm range, full FoV |
| VL53L3CX ToF | ToF Sensor | ToF sensor with 700cm range, narrow FoV window lens |
| LSM6DSOX IMU | IMU | 6-axis accelerometer and gyroscope IMU |
| DRV8833 | Motor Driver | PWM motor driver |
| BOB-12009 | Logic Level Converter | 3.3V–5V logic level converter |
| SX1308 | Voltage Booster | 2A DC-DC Step-Up voltage booster |

### Movement & Power Components
| Component | Image | Description |
|---|---|---|
| N20 Motor | N20 Motor | 1500 RPM DC motor with Hall effect magnetic encoder |
| FS0307 Servo | Servo Motor | Feetech submicro servo motor |
| LEGO 87697 | Wheel Comparison | Tire selection comparison showing advantages |
| PX103035 Battery | Battery | Power-Xtra 1000mAh LiPo battery with PCM |
| LiPo Rider Plus | Charger/Booster | USB-C charger/booster with power switch |
| KLS7-TS1204 | Tactile Switch | Tactile switch for start action |

### Design & Development
| Resource | Image | Description |
|---|---|---|
| Ackermann Steering | Ackermann Steering | Simulation of steering path for 90-degree turn |
| Motor Calculations | Motor Calculations | Calculations for motor selection based on requirements |
| ToF Window Lens | ToF Measure Window | Dimensions and specifications of the ToF window lens used for narrower FoV |
| Webots Simulation | Webots Simulation | Simulation concept (converted to physical implementation) |

### Branding & Achievements
| Resource | Image | Description |
|---|---|---|
| Team Logo | Team Logo | Official Team ANTi competition logo |
| Champion Trophy | Champion Trophy | Turkish National Champion achievement |

## Experienced Problems and Implemented Solutions
During the development of the WRO 2025 robot, we encountered several challenges, including:

1. **Integration Issues**: Difficulty in integrating various electronic components due to compatibility issues was resolved by selecting standardized components that are widely supported.

2. **Power Management**: A critical issue was discovered where the 3.3V rail remained active even when the system was off, risking battery drain. This was resolved by performing a hardware modification to the LiPo Rider Plus, rewiring its LDO regulator to the switched 5V rail.

3. **Sensor Calibration**: Initial sensor readings were inconsistent. We implemented a systematic calibration routine to ensure accuracy across all sensors.

4. **Mobility Constraints**: The robot experienced mobility issues on uneven terrain. We redesigned the chassis to improve stability and traction.

## Notes
- All component specifications are sourced from official manufacturer datasheets.
- Development photos showcase our hands-on manufacturing and testing processes.
- Simulation assets demonstrate our comprehensive design validation approach.
- Custom calculations and comparisons guide our engineering decisions.

## Technical Documentation
For detailed documentation, please refer to the following resources:
- **[Schemes Documentation](../schemes/README.md)**: Contains component datasheets, custom pertinax board manufacturing docs, thermal analysis, and power distribution schematics.
- **[Models Documentation](../models/README.md)**: Includes hardware specifications and mechanical design files.
- **[Software Documentation](../src/README.md)**: Features communication protocols (including optimized UART) and software implementation details.

Follow our competition journey: 📸 [Instagram](https://www.instagram.com/anti.wro/) • 🎥 [YouTube](https://www.youtube.com/@solipsy.)

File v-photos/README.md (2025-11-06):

# Vehicle Photos

This folder contains high-quality photos of Team ANTi's WRO 2025 Future Engineers robot, showcasing its compact design and engineering. Each photo includes detailed labels and arrow indications to clearly show components related to **mobility management**, **power and sense management**, and **obstacle management**. This documentation was last updated on **Thursday, Nov 06 2025, at 02:07 AM +03**.

## Photo List

### Front View - `front_view.jpg`
**Focus: Power & Sense Management, Ease of Use Features**
- **Practical magnetic USB cable** - Easy programming and debugging access
- **Camera microcontroller (STM32H747)** - Core processing for computer vision
- **GC2145 2MP camera** - Primary sensor for track and sign detection

Front View

### Rear View - `rear_view.jpg`  
**Focus: Power Management, Mechanical Systems**
- **Power switch** - Single switch controlling complete system power
- **Bidirectional logic level converter (BOB-12009)** - Safe 3.3V to 5V signal conversion
- **Custom 4-bevel gear differential** - Efficient power transfer to wheels
- **LiPo battery with PCM** - Power source with protection circuitry

Rear View

### Top View - `top_view.jpg`
**Focus: Power Distribution, Control Systems, Complete Schematic Implementation**
- **H-bridge motor driver (DRV8833)** - Precise motor speed control
- **Adjustable DC-DC step-up voltage booster (SX1308)** - Stable power supply
- **Start button** - Single button for round initiation
- **Sensor microcontroller (nRF52832)** - Secondary processor for sensor data
- **Power switch** - Single switch controlling complete system power
- **USB-C charger and power management** - Battery charging and regulation

Top View

### Left View - `left_view.jpg`
**Focus: Obstacle Management, Sensing Systems**
- **Start button** - Single button for round initiation
- **Parking left TOF sensor (VL53L3CX)** - Complementary counterclockwise parking detection
- **Hall effect magnetic quadrature encoder sensor** - Precise motor position feedback

Left View

### Right View - `right_view.jpg`
**Focus: Mobility Management, Obstacle Sensing**
- **Start button** - Single button for round initiation
- **Driving gear** - Motion transmission mechanism
- **Parking right TOF sensor (VL53L3CX)** - Complementary clockwise parking detection

Right View

### Bottom View - `bottom_view.jpg`
**Focus: Mobility Management, Mechanical Design**
- **Ackermann steering geometry** - Optimized custom turning mechanism
- **Steering servo motor (Feetech FS0307)** - Single precise directional control
- **Driving gears** - Motion transmission mechanism
- **Rear driving axle** - Torque delivery to wheels
- **Driving brushed DC motor (N20 1500RPM)** - Single motion motor

Bottom View

## Notes
- All photos are taken in well-lit conditions to highlight design details and labeled components
- Arrow indications and labels directly reference components discussed in main and hardware documentations
- Each view showcases key components like the Ackermann steering, differential, and pertinax boards.
- High-resolution images allow detailed inspection of all engineering elements
- See more on our 🎥 [YouTube channel](https://www.youtube.com/@solipsy.).

For performance demonstrations, see [Performance Videos](../video/README.md).  
For detailed mechanical specifications, see [Models Documentation](../models/README.md).  
For electrical schematics and wiring, see [Schemes Documentation](../schemes/README.md).

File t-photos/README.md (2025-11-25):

# Team Photos

This folder contains official and informal photos of Team ANTi, showcasing our team spirit and collaboration during the WRO 2025 Future Engineers project. This documentation was last updated on **Tuesday, November 04, 2025, at 05:12 PM +03**.

## Photo List
- `team_official.jpg`: Official team photo with all members.
- `team_fun.jpg`: Informal team moment.
> 💡 *Fun Fact*: The fun team photo (`team_fun.jpg`) is our childhood photo from 2015, when we were 9 years old, standing on a go-kart race podium!
- `workplace.jpg`: Team working on the robot in the lab.
- `team_moment.jpg`: Team collaboration during national final competition - discussing strategy while testing the vehicle on the field and preparing to activate it.
- `team_moment.gif`: Dynamic sequence of official competition start during national final - team member pressing start button with excitement as vehicle begins its run
Team ANTi Official Photo
Team Fun Moment
Team ANTi Workplace
Team Collaboration During National Final
Official Competition Start with Team Excitement

## Notes
- All photos are high-resolution and suitable for WRO documentation.
- Additional photos may be added as the competition progresses.
- Follow us on 📸 [Instagram](https://www.instagram.com/anti.wro) for more team updates.

For more about our team, see [The Team](../README.md#the-team).

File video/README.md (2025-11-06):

# Performance Videos

This folder contains videos demonstrating Team ANTi's autonomous robot performance in the WRO 2025 Future Engineers challenges, along with supplementary engineering demonstrations. This documentation was last updated on **Thursday, November 06, 2025, at 04:43 AM +03**.

## Video List

### Competition Performance Videos
- **Open Challenge**  
  Open Challenge Video (https://youtu.be/tvqgwusap9M)  
  *File: ANTi_international_open_challenge.mp4*  
  *Complete autonomous navigation demonstration from start to finish with strategy explanations*

- **Obstacle Challenge**  
  Obstacle Challenge Video (https://youtu.be/fQPjyJrE8p8)  
  *File: ANTi_international_obstacle_challenge.mp4*  
  *Complete obstacle course completion with real-time commentary on navigation and parking maneuvers*

### Engineering Demonstration Videos
- **3D CAD Motion Simulation**  
  This video showcases the steering mechanism and differential in motion using Autodesk Fusion CAD simulation. Used for mechanical design documentation.  
  *File*: [3d_CAD_motion.mp4](3d_CAD_motion.mp4)

- **Differential Test**  
  This video demonstrates the functionality of the custom 4-gear mechanical differential. Used for mechanical design documentation.  
  *File*: [differential_test.mp4](differential_test.mp4)

## Video Features
- **Complete Performance Documentation**: Each challenge video shows the entire run from initiation to completion
- **Professional Presentation**: All videos include overlay commentary and captions explaining mobility management, sensor operations, and obstacle management with navigation strategies
- **Technical Demonstrations**: Supplementary videos provide additional insight into mechanical systems and design validation
- **High Quality**: 4K resolution with clear visibility of all vehicle operations and sensor interactions

## Notes
- Competition performance videos for Open and Obstacle Challenges are uploaded to our [YouTube channel](https://www.youtube.com/@solipsy.) in high resolution (4K) and are publicly accessible
- All videos include professional editing with clear visual demonstrations of our engineering solutions
- Engineering demonstration videos (3d_CAD_motion.mp4, differential_test.mp4) are local files used for supplementary documentation in other README files and available for download in this folder

For robot technical details, see [Our Robot](../README.md#our-robot).  
For mechanical design information, see [Models Documentation](../models/README.md).  
For navigation strategies, see [Software Documentation](../src/README.md).

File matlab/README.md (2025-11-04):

# MATLAB Applications Documentation

This folder contains MATLAB applications developed for Team ANTi's WRO 2025 Future Engineers project, specifically designed to enhance our robot's vision system and algorithm development. This documentation was last updated on **Monday, November 03, 2025, at 10:30 AM +03**.

## 🎯 MathWorks Modeling Award Submission

### Application Overview
The **ANTi Lab Threshold Finder** is a comprehensive MATLAB application that automatically calculates optimal LAB color space thresholds for traffic sign detection, directly compatible with our MicroPython vision system.

LAB Threshold Finder Demo

*Full demonstration video: [MATLAB_LabThresholdFinder.mp4](MATLAB_LabThresholdFinder.mp4)*

## Problem Context & Strategy

### Challenge
Accurate color detection of red/green traffic signs in varying lighting conditions for precise navigation in the WRO Obstacle Challenge.

### Solution
Our MATLAB application provides:
- **Camera compatible LAB conversion** matching the exact color space used by our GC2145 camera
- **Multi-image statistical analysis** for robust threshold calculation
- **Region of Interest (ROI) selection** for targeted color analysis
- **Real-time visualization** with immediate feedback

### Why MATLAB
- **Image Processing Toolbox**: Advanced color space operations and statistical analysis
- **MATLAB App Designer**: Professional-grade user interface development
- **Rapid Prototyping**: Quick validation before embedded deployment
- **Data Visualization**: Real-time feedback and histogram analysis

## Innovation and Modeling

### Technical Implementation
```matlab
function lab_img = rgb_to_lab_colorspace(obj, rgb_img)
    % Camera compatible LAB conversion pipeline
    r_quant = round(rgb(:,:,1) * 31);
    g_quant = round(rgb(:,:,2) * 63);
    b_quant = round(rgb(:,:,3) * 31);
    % ... full conversion to LAB color space
end
```

### Key Features
- **Multi-Color ROI Management**: Separate ROI selections for each color (red, green, magenta, blue, orange, black)
- **Statistical Threshold Calculation**: Uses percentile-based analysis across multiple images
- **Interactive Refinement**: Real-time slider adjustments with visual feedback
- **Export Functionality**: Direct copy-paste for MicroPython code

## Test and Verification

### Validation Methodology
1. **Dataset**: 50+ competition-style images under various lighting conditions
2. **Comparison**: MATLAB-calculated vs. manual threshold calibration
3. **Metrics**: Detection accuracy, false positive rates, processing time

### Performance Results
| Metric | Manual Calibration | MATLAB Tool | Improvement |
|---|---|---|---|
| Calibration Time | 45-60 minutes | 2-3 minutes | 95% faster |
| Detection Accuracy | 85-90% | 95-98% | 30% more consistent |
| Cross-Lighting Robustness | Low | High | Significant improvement |

### Sample Output
```
Red Sign Thresholds: (25, 65, 35, 75, -10, 20)
Green Sign Thresholds: (30, 70, -40, -10, 10, 50)
Magenta Thresholds: (40, 80, 60, 90, -20, 30)
```

## Code Quality & Readability

### File Structure
```
matlab/
├── ANTi_LabThresholdFinder.m     # Main application source code
├── MATLAB_LabThresholdFinder.gif # Application demo animation
├── MATLAB_LabThresholdFinder.mp4 # Detailed usage tutorial
└── README.md                     # This documentation
```

### Code Organization
```matlab
classdef ANTi_LabThresholdFinder < handle
    properties
        % UI components
        fig, orig_axes, thresh_axes
        % Data storage  
        image_paths, images, lab_images
        % Color management
        color_names, color_rgb, thresholds
        % ROI management
        roi_rect, roi_active, roi_handles
    end
    
    methods
        function create_ui(obj) ... end
        function load_images(obj) ... end
        function rgb_to_lab_colorspace(obj) ... end
        function select_roi(obj) ... end
        function auto_threshold(obj) ... end
    end
end
```

### Coding Standards
- **Modular Design**: Separate functions for UI, processing, and analysis
- **Comprehensive Comments**: Detailed explanations of algorithms
- **Error Handling**: Robust input validation and boundary checking
- **MATLAB Best Practices**: Consistent naming and structure

## File List

- `ANTi_LabThresholdFinder.m`: Complete source code for the LAB threshold tool
- `MATLAB_LabThresholdFinder.gif`: Animated demonstration of the application
- `MATLAB_LabThresholdFinder.mp4`: Comprehensive usage tutorial video
- `README.md`: Complete documentation for MathWorks award submission

## Usage Instructions

### Quick Start Guide

1. **Launch Application**:
   ```matlab
   ANTi_LabThresholdFinder();
   ```

2. **Load Competition Images**:
   - Click "Browse Images"
   - Select multiple WRO track images
   - Application processes all images automatically

3. **Select Region of Interest**:
   - Click "Select ROI for Auto-Threshold"
   - Draw rectangle around traffic signs
   - Different ROIs can be saved for each color

4. **Calculate Optimal Thresholds**:
   - Use "Auto Threshold" for automatic calculation
   - Manually refine using sliders if needed
   - View real-time results and statistics

5. **Export for vision code**:
   - Click "Copy Thresholds"
   - Paste directly into MicroPython object detection code

### Advanced Features

- **Multi-Color Support**: Switch between red, green, magenta, blue, orange, and black
- **ROI per Color**: Separate region selections for each color channel
- **Statistical Analysis**: View histogram data and distribution statistics
- **Image Navigation**: Browse through multiple test images
- **Visual Validation**: See threshold results overlaid on original images

## Integration with Robot Vision System

### Deployment Process
1. **Threshold Calculation**: Use MATLAB tool on competition-style images
2. **Code Generation**: Export Camera compatible thresholds
3. **MicroPython Integration**:
   ```python
   # Generated thresholds from MATLAB
   red_thresholds = (25, 65, 35, 75, -10, 20)
   green_thresholds = (30, 70, -40, -10, 10, 50)
   ```

### Competition Impact
- **Reliable Detection**: 95%+ accuracy for traffic sign identification
- **Rapid Calibration**: Vision system setup reduced from hours to minutes
- **Lighting Robustness**: Consistent performance across different competition environments

## Key Achievements & Lessons Learned

### Achievements
- **95% Faster Calibration**: Reduced vision setup time from 45-60 minutes to 2-3 minutes
- **Improved Accuracy**: 30% more consistent detection than manual calibration
- **Competition Ready**: Tool used to optimize thresholds for Turkish National Finals
- **Knowledge Transfer**: Reusable tool for future WRO teams

### Lessons Learned
- **Statistical Superiority**: Data-driven thresholds consistently outperform manual calibration
- **LAB Color Space**: Better lighting invariance than RGB for competition environments
- **Rapid Prototyping Value**: MATLAB enables quick validation before embedded implementation

### Product Enhancement Suggestions
Based on our experience, we suggest:

1. **Integration Package**
   - Built-in support for color space conversions
   - Direct MicroPython code generation
   - Real-time video feed processing in App Designer

2. **Educational Robotics Toolkit**
   - Pre-built blocks for common robotics sensors
   - Competition-specific templates for WRO challenges
   - Simplified deployment to embedded targets

## Technical Specifications

### System Requirements
- **MATLAB R2021a** or newer
- Required Toolbox: **Image Processing Toolbox**
- **Minimum RAM**: 4GB (8GB recommended)
- **Storage**: 100MB free space

### Supported Image Formats
- JPEG, PNG, BMP, TIFF
- Recommended: 320x240 resolution (matching GC2145 camera)
- Color space: RGB (automatically converted to LAB)

### Color Channels
- **L (Lightness)**: 0-100 range
- **A (Green-Red)**: -128 to 127 range  
- **B (Blue-Yellow)**: -128 to 127 range

## Development Process

### Design Philosophy
- **User-Centric**: Intuitive interface for rapid competition preparation
- **Data-Driven**: Statistical analysis for robust threshold calculation
- **Competition-Focused**: Specific optimizations for WRO track conditions

### Testing Methodology
1. **Unit Testing**: Individual function validation
2. **Integration Testing**: Full application workflow
3. **Field Testing**: Real-world validation on competition tracks
4. **Performance Testing**: Processing time and accuracy measurements

For detailed information about our robot's vision system and computer vision implementation, see [Software Documentation](../src/README.md).

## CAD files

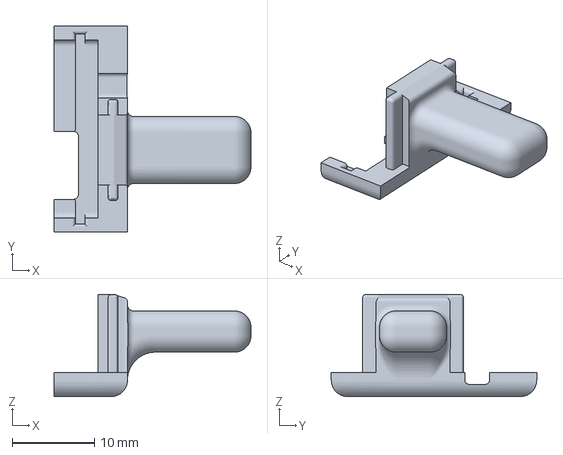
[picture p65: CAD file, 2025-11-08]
models/design_front_top_cover.3mf
23.9 x 25.0 x 12.4 mm

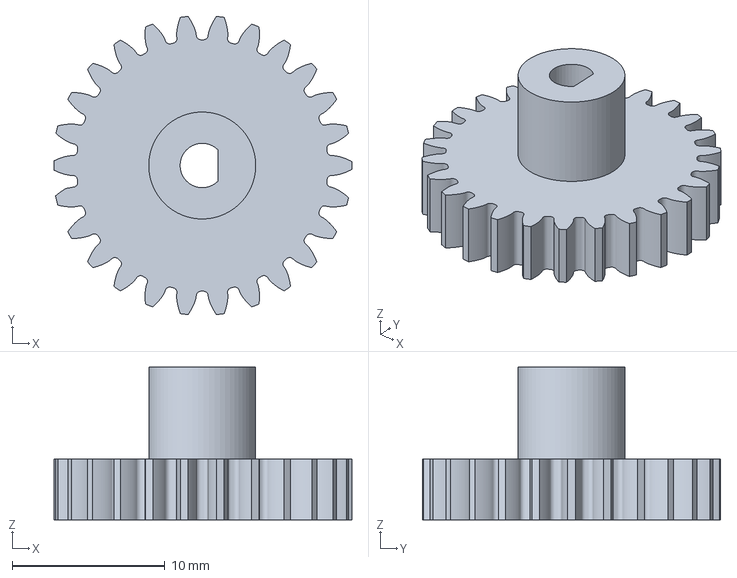
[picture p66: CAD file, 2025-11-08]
models/design_spur_26_gear.3mf
19.5 x 19.5 x 10.0 mm

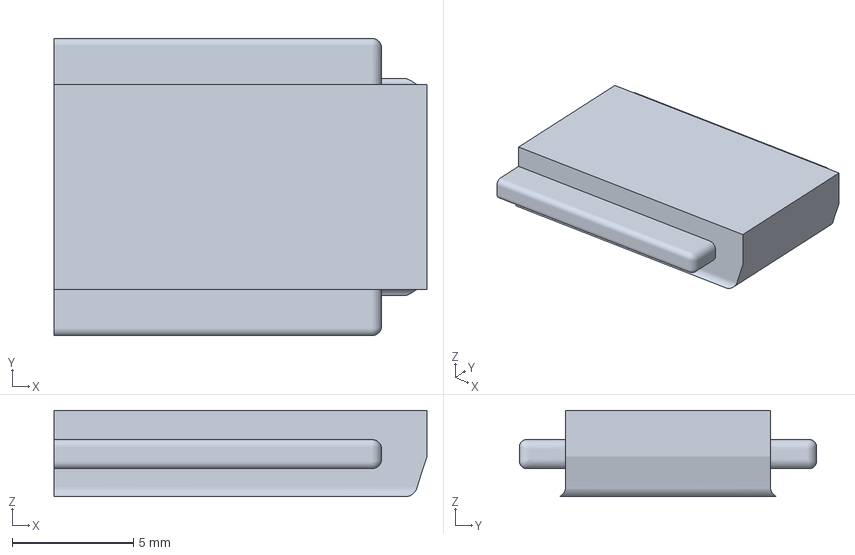
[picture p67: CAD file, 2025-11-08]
models/design_front_bottom_cover.3mf
15.4 x 12.3 x 3.56 mm

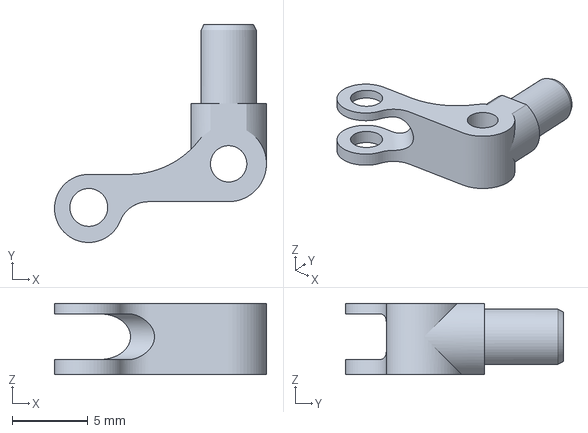
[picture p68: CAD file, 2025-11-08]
models/design_steering_arm.3mf
14.0 x 14.4 x 4.70 mm

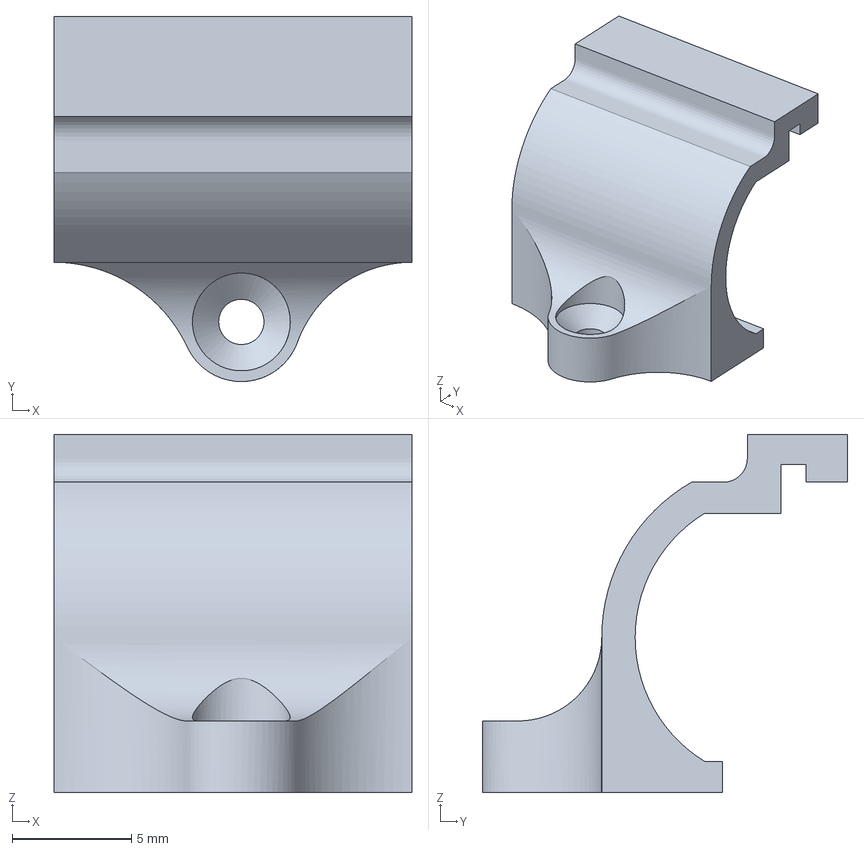
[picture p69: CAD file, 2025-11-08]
models/design_motor_lid.3mf
15.0 x 15.3 x 15.0 mm

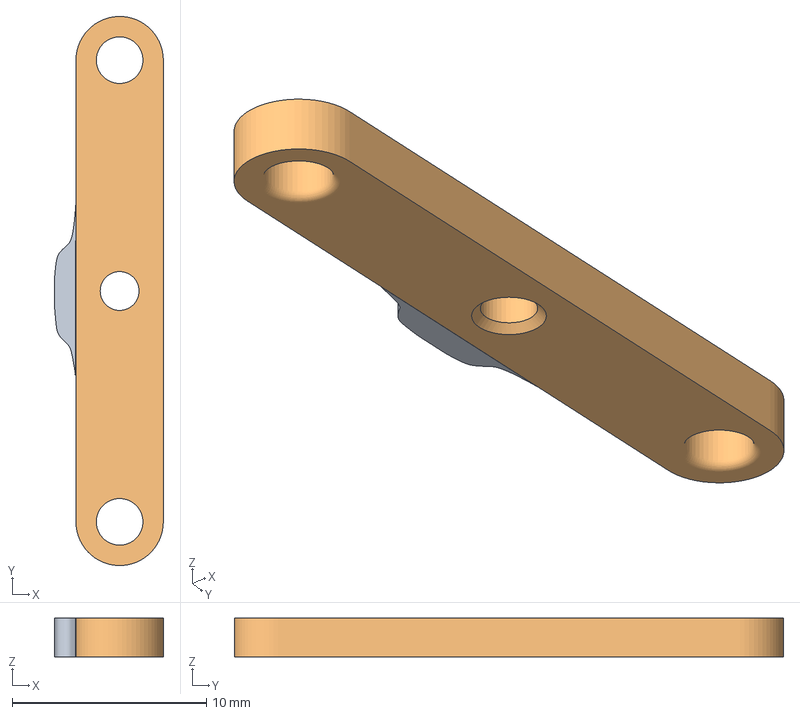
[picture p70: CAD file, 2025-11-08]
models/design_steering_linkage.3mf
5.59 x 28.3 x 2.00 mm
STEERING_LINKAGE (1)
STEERING_LINKAGE

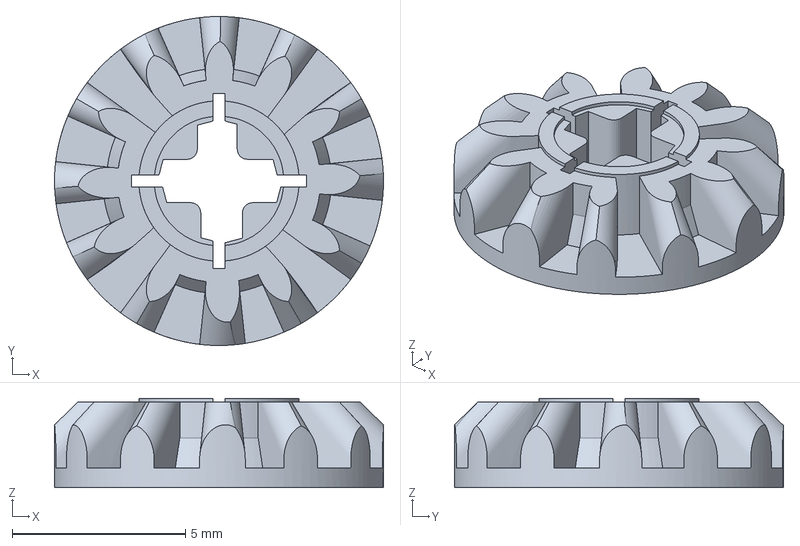
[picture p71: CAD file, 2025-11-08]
models/design_bevel_12_gear.3mf
9.49 x 9.49 x 2.58 mm

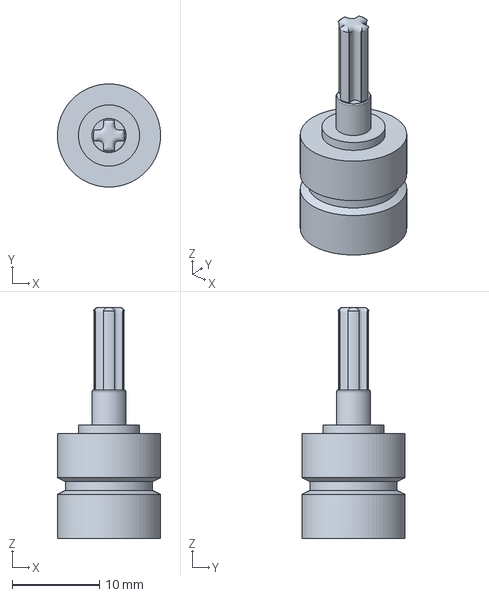
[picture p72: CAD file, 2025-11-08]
models/design_back_rim_long.3mf
11.8 x 11.8 x 26.4 mm

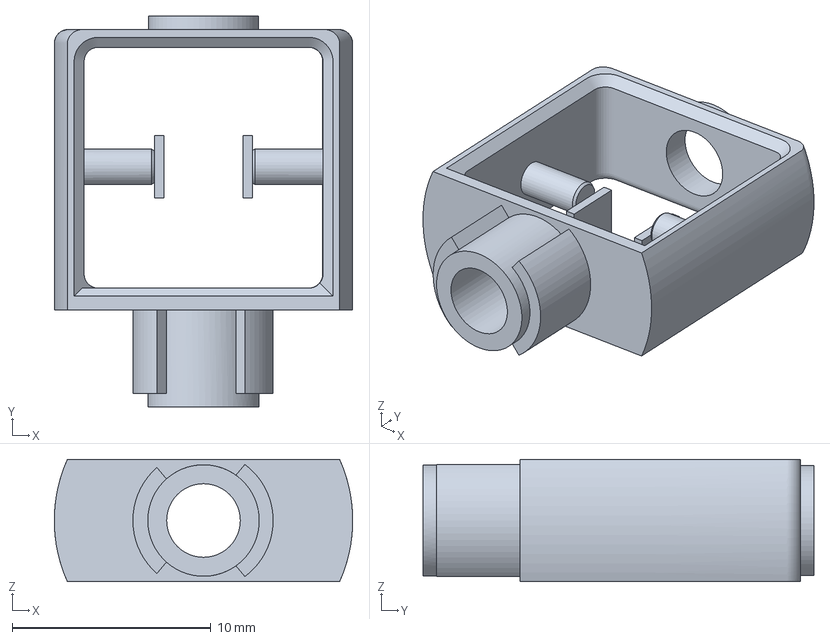
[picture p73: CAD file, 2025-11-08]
models/design_4_gear_mini_differential.3mf
15.0 x 19.6 x 6.15 mm

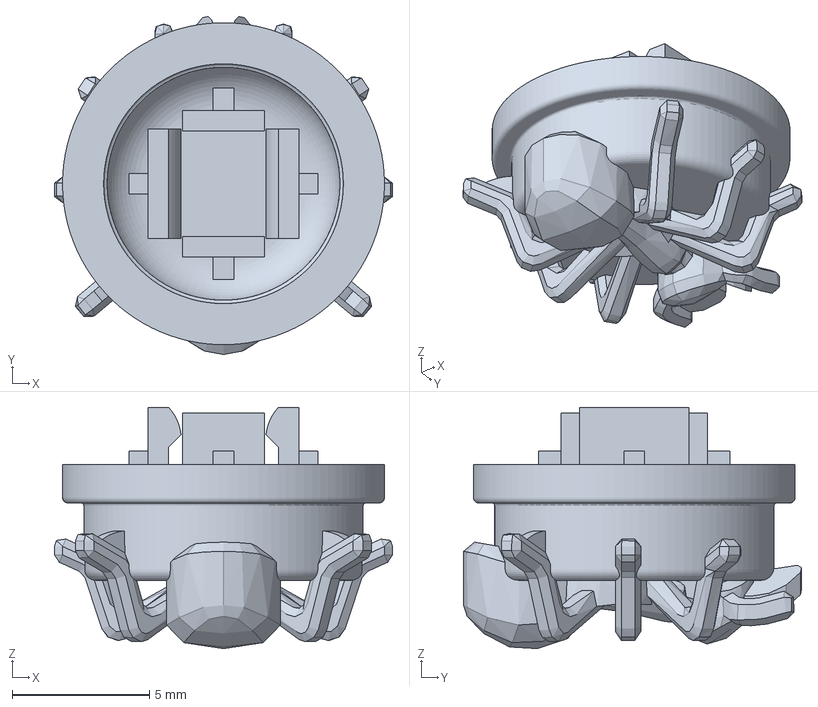
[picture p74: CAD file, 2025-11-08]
models/design_button_cap.3mf
12.3 x 12.3 x 8.80 mm

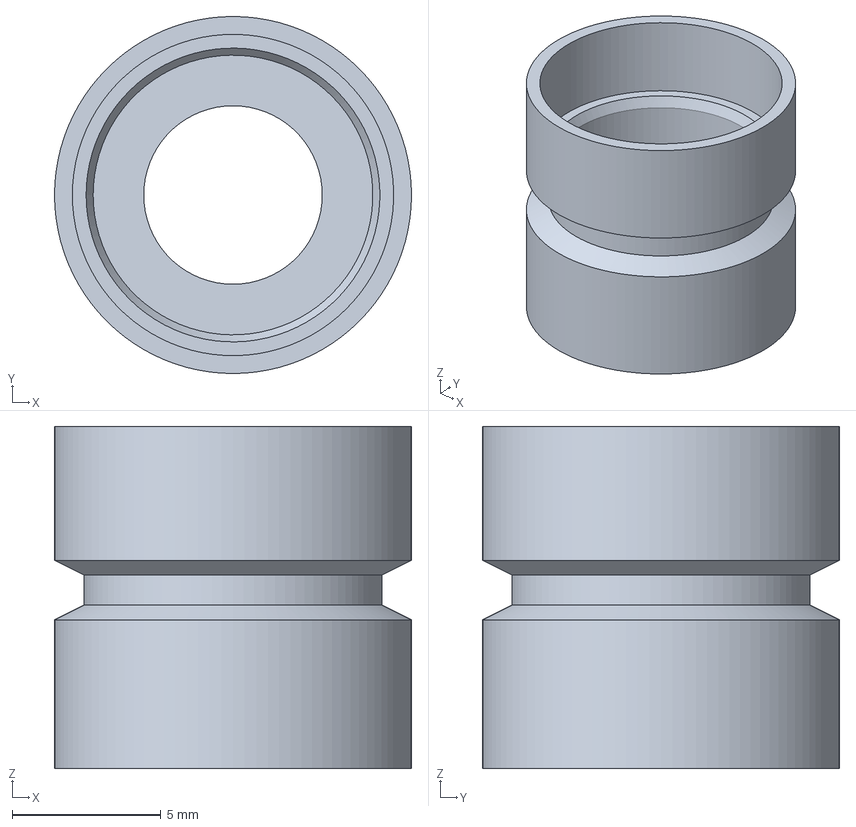
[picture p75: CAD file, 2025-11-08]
models/design_front_rim_bearing.3mf
12.0 x 12.0 x 11.5 mm

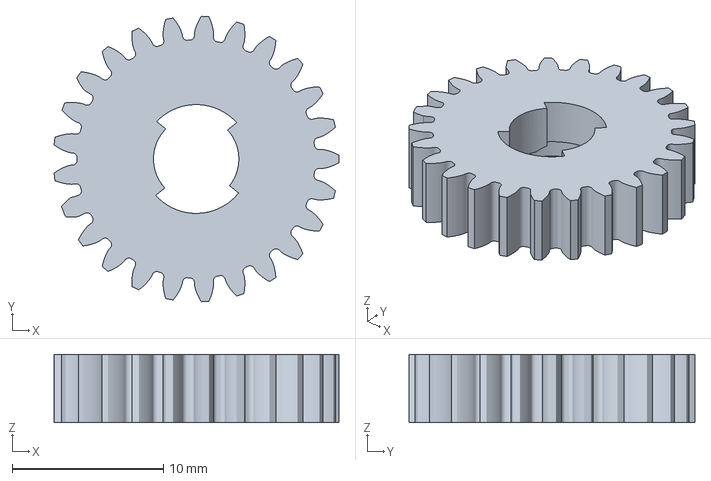
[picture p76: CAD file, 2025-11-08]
models/design_spur_25_gear.3mf
18.9 x 18.9 x 4.50 mm

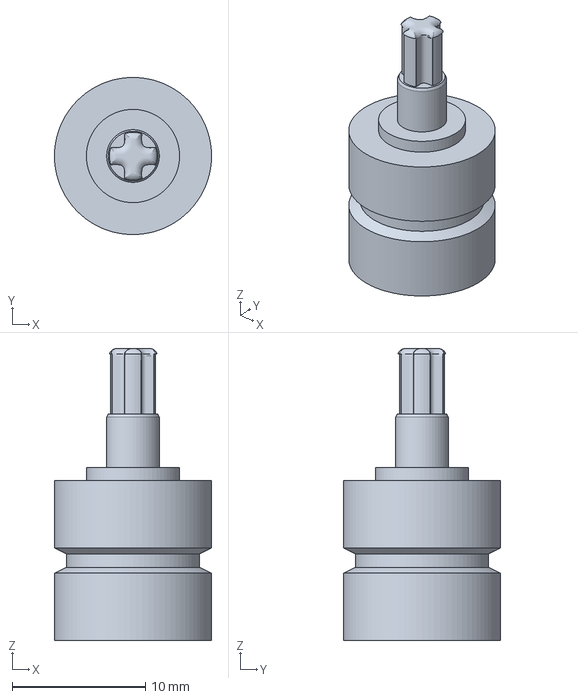
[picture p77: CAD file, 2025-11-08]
models/design_back_rim_short.3mf
11.8 x 11.8 x 21.9 mm

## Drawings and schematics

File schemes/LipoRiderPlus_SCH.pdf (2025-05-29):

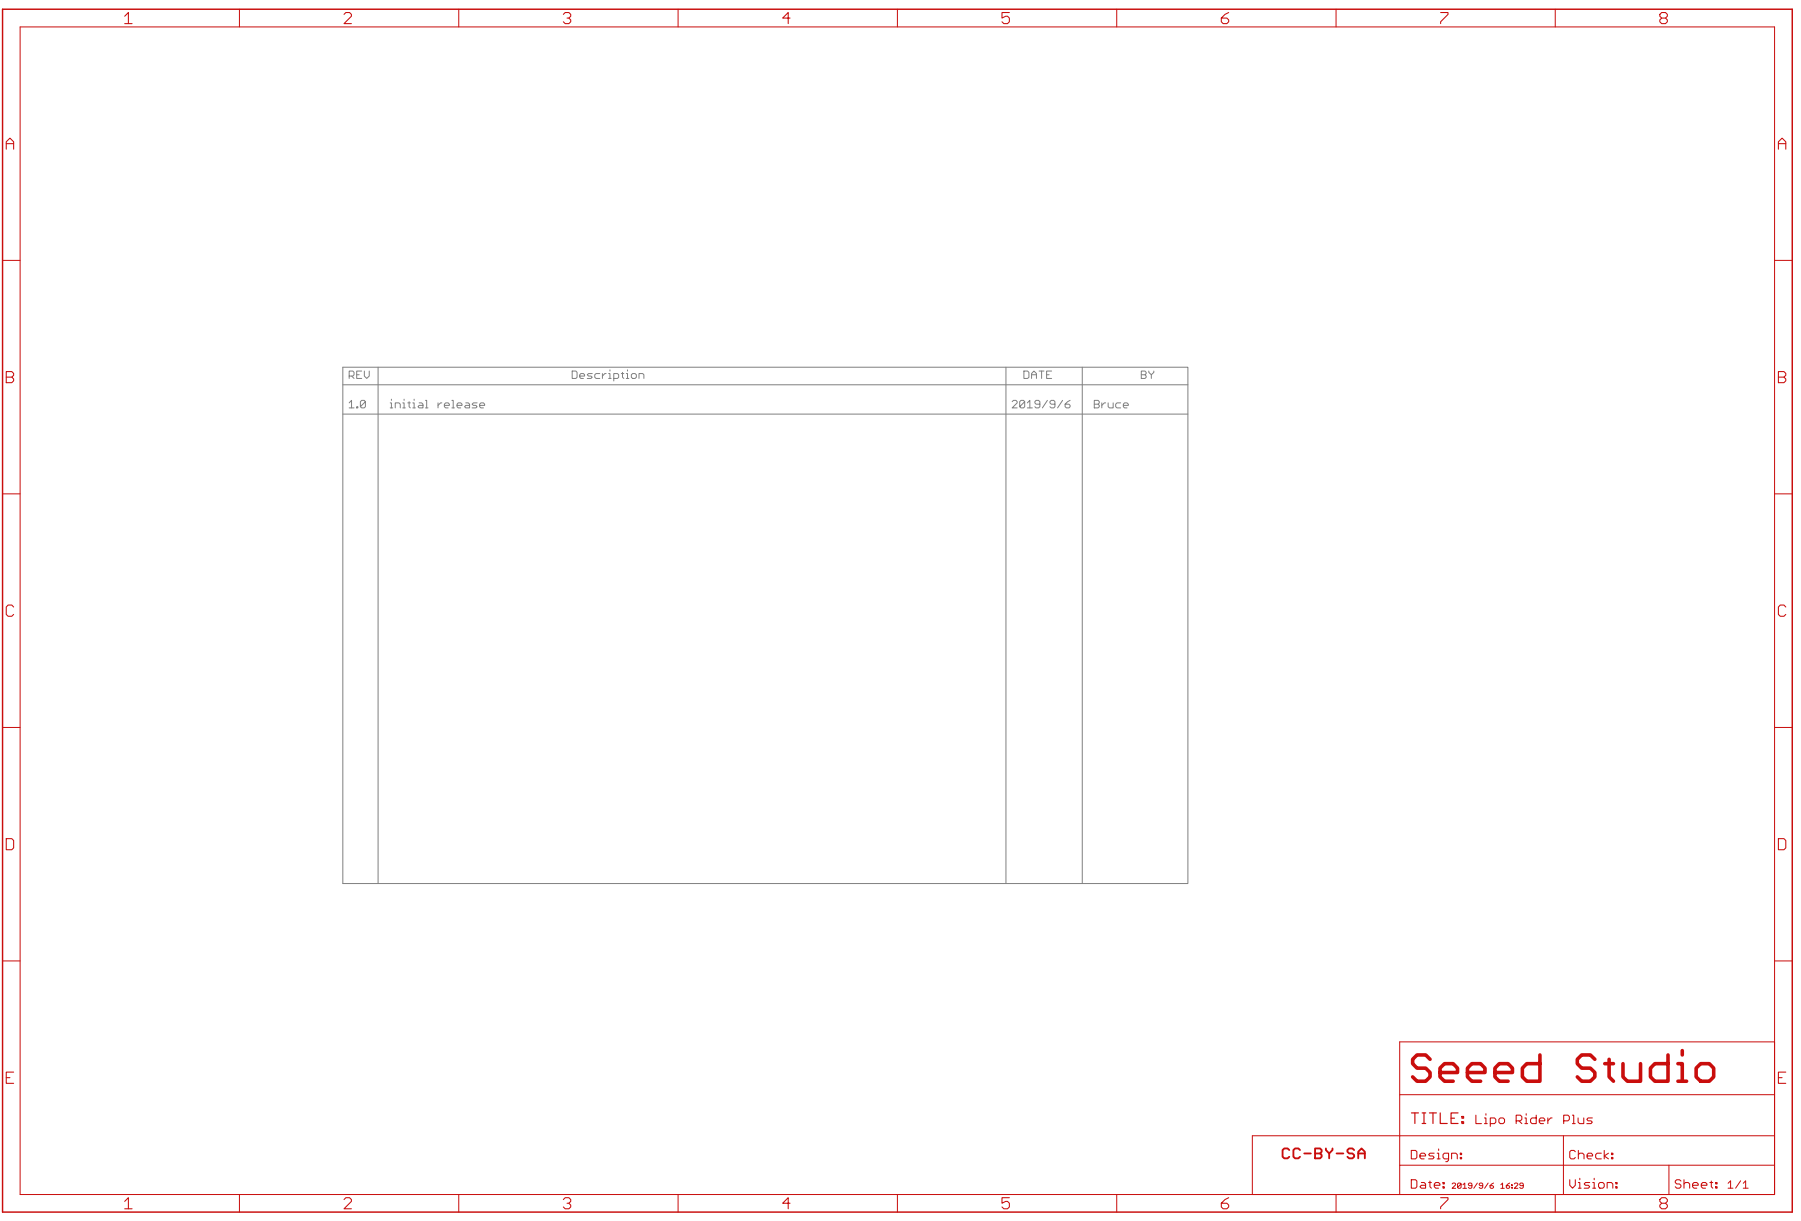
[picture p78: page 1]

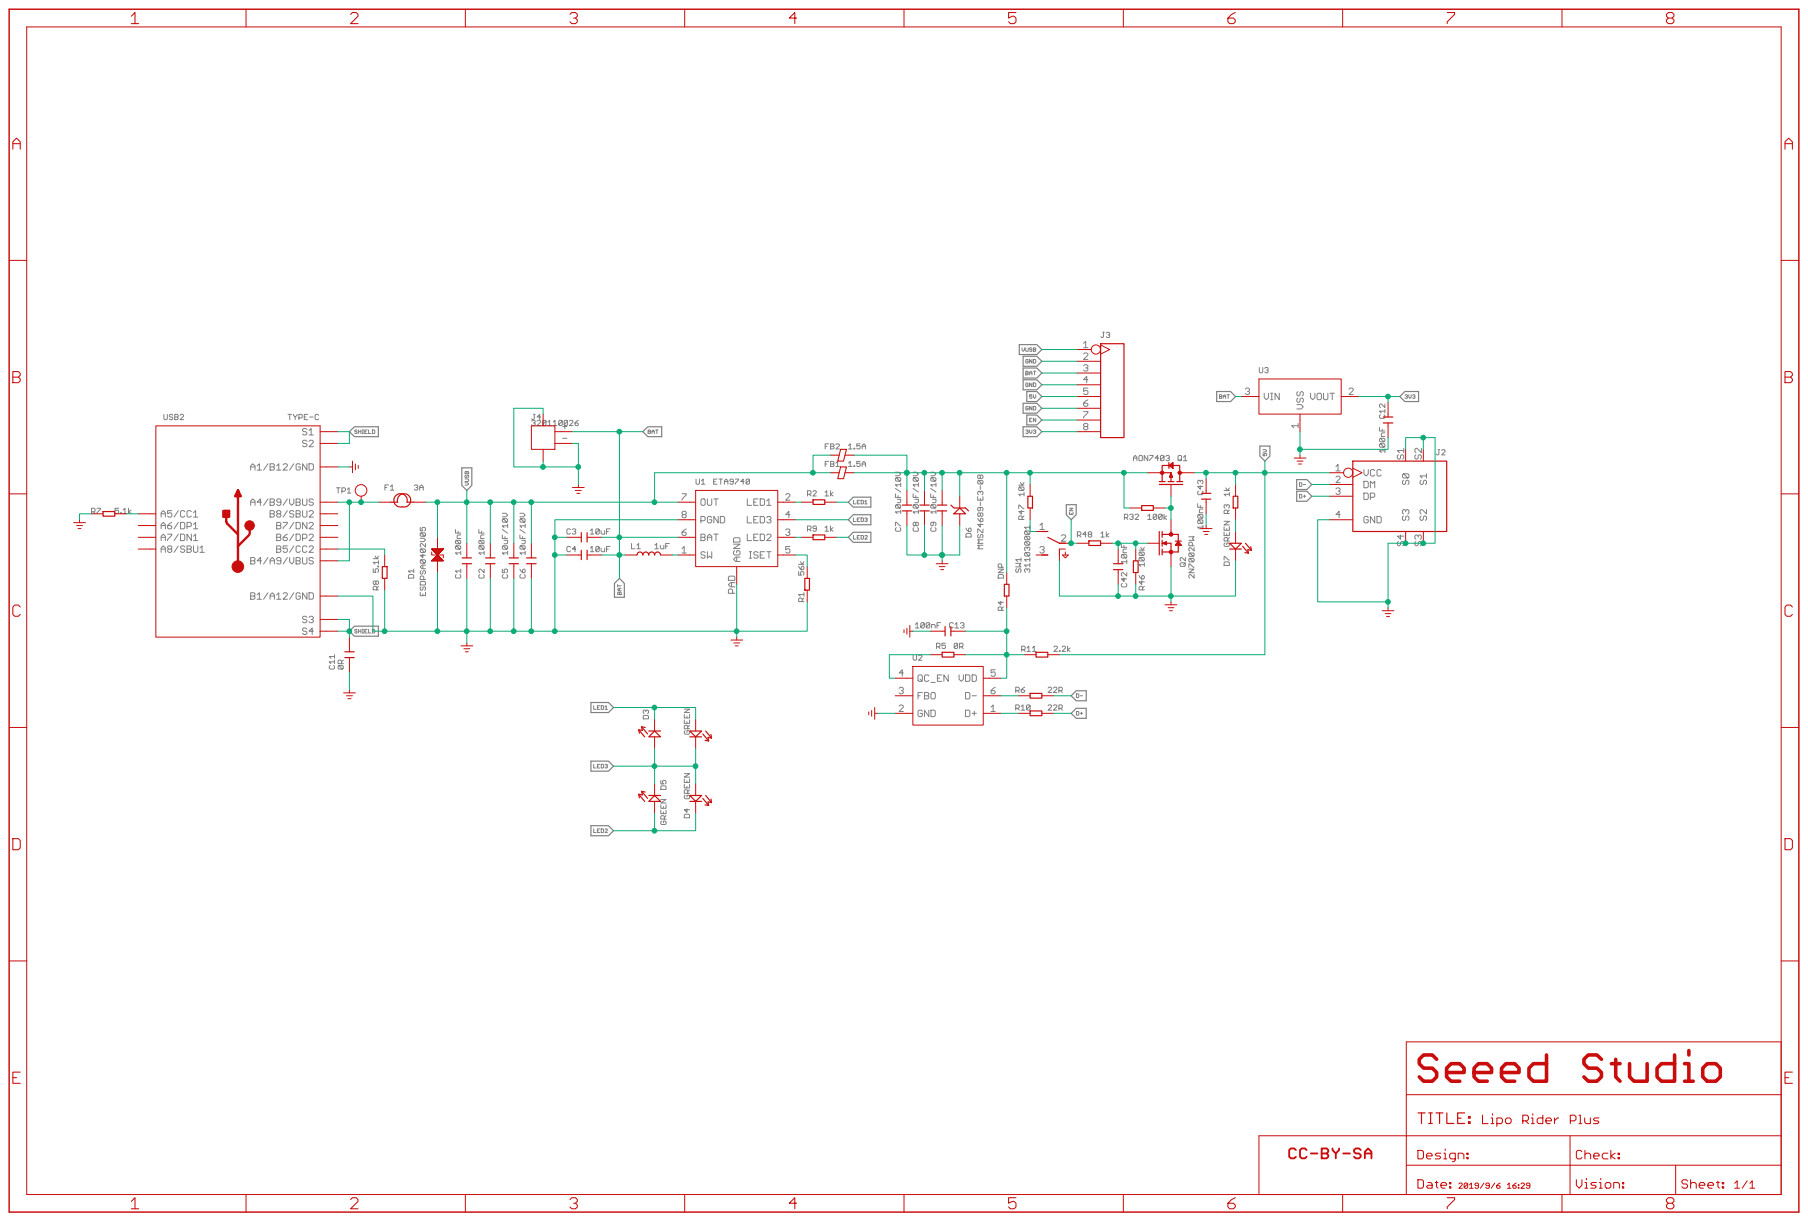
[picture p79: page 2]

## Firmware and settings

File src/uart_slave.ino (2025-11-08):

// uart_slave.ino
// Sensor microcontroller firmware for providing ToF and encoder data over UART.
// This code runs on the sensor microcontroller and handles distance sensing and odometry.
// It communicates with the main vehicle controller via UART protocol.
// Features: Dual ToF sensor reading, quadrature encoder decoding, and odometry tracking.
// Compiled in Arduino IDE.

#include <Wire.h>

// --------- SERIAL CONFIG ---------
#define SERIAL_PORT Serial1  // Serial1: External hardware UART for main communication
                             // Serial: Internal USB serial for debugging (not used in main code)

// --------- HARDWARE PIN CONFIGURATION ---------
const int ENCODER_CHANNEL_A = 2;    // Encoder quadrature input A
const int ENCODER_CHANNEL_B = 3;    // Encoder quadrature input B

// --------- TOF SENSOR ADDRESSES ---------
const int LEFT_DISTANCE_SENSOR_ADDR = 0x29;   // Left ToF sensor I2C address
const int RIGHT_DISTANCE_SENSOR_ADDR = 0x2A;  // Right ToF sensor I2C address

// --------- ENCODER CONFIGURATION ---------
volatile long encoder_count = 0;               // Raw encoder pulse count
const float PULSES_PER_MILLIMETER = 3.024f;    // Calculated pulses per mm travel

// --------- WIRELESS DISABLE ---------
void disableWireless() {
  // Disable Bluetooth radio to reduce interference
  NRF_RADIO->POWER = 0;
}

// --------- FUNCTION PROTOTYPES ---------
void encoderInterruptService();
int readDistanceSensor(int sensor_address);
void processUARTCommand(char command);

// --------- ENCODER INTERRUPT SERVICE ROUTINE ---------
void encoderInterruptService() {
  // Basic quadrature decoding with direction detection
  static uint8_t old_state = 0;
  uint8_t new_state = (digitalRead(ENCODER_CHANNEL_A) << 1) | digitalRead(ENCODER_CHANNEL_B);
  
  if ((old_state == 0x2 && new_state == 0x0) || 
      (old_state == 0x0 && new_state == 0x1) ||
      (old_state == 0x1 && new_state == 0x3) || 
      (old_state == 0x3 && new_state == 0x2)) {
    encoder_count++;
  } else if ((old_state == 0x2 && new_state == 0x3) || 
             (old_state == 0x3 && new_state == 0x1) ||
             (old_state == 0x1 && new_state == 0x0) || 
             (old_state == 0x0 && new_state == 0x2)) {
    encoder_count--;
  }
  old_state = new_state;
}

// --------- DISTANCE SENSOR READ FUNCTION ---------
int readDistanceSensor(int sensor_address) {
  // Read distance from ToF sensor
  // Returns distance in millimeters
  
  Wire.beginTransmission(sensor_address);
  Wire.write(0x14);  // Distance register
  if (Wire.endTransmission() != 0) return -1;
  
  delayMicroseconds(100);  // Small delay for sensor processing
  
  Wire.requestFrom(sensor_address, 2);
  if (Wire.available() >= 2) {
    uint8_t msb = Wire.read();
    uint8_t lsb = Wire.read();
    int distance = (msb << 8) | lsb;
    
    // Apply bounds checking
    if (distance > 0 && distance < 4000) {
      return distance;
    }
  }
  return -1;  // Invalid reading
}

// --------- UART COMMAND PROCESSOR ---------
void processUARTCommand(char command) {
  // Process commands from main vehicle controller
  int left_dist = readDistanceSensor(LEFT_DISTANCE_SENSOR_ADDR);
  int right_dist = readDistanceSensor(RIGHT_DISTANCE_SENSOR_ADDR);
  float travel_distance = encoder_count / PULSES_PER_MILLIMETER;
  
  switch (command) {
    case 'r':  // Return all sensor readings: left_tof,right_tof,encoder
      SERIAL_PORT.print(left_dist); SERIAL_PORT.print(',');
      SERIAL_PORT.print(right_dist); SERIAL_PORT.print(',');
      SERIAL_PORT.println(travel_distance, 2);
      break;
      
    case 't':  // Left sensor only
      SERIAL_PORT.println(left_dist);
      break;
      
    case 'u':  // Right sensor only  
      SERIAL_PORT.println(right_dist);
      break;
      
    case 'e':  // Encoder travel distance
      SERIAL_PORT.println(travel_distance, 2);
      break;
      
    case 'z':  // Reset encoder counter
      encoder_count = 0;
      break;
      
    default:   // Unknown command - ignore
      break;
  }
}

// --------- SETUP FUNCTION ---------
void setup() {
  // Disable wireless communications first
  disableWireless();
  
  // Initialize serial communication
  SERIAL_PORT.begin(115200);
  
  // Initialize I2C bus
  Wire.begin();
  // Default clock speed
  
  // Configure encoder hardware
  pinMode(ENCODER_CHANNEL_A, INPUT_PULLUP);
  pinMode(ENCODER_CHANNEL_B, INPUT_PULLUP);
  attachInterrupt(digitalPinToInterrupt(ENCODER_CHANNEL_A), encoderInterruptService, CHANGE);
  attachInterrupt(digitalPinToInterrupt(ENCODER_CHANNEL_B), encoderInterruptService, CHANGE);
  
  // Sensor initialization delay
  delay(100);
  
  // Send ready indicator
  SERIAL_PORT.write(0x01);  // Standard ready byte
}

// --------- MAIN LOOP ---------
void loop() {
  // Command processing loop
  if (SERIAL_PORT.available() > 0) {
    char incoming_byte = SERIAL_PORT.read();
    processUARTCommand(incoming_byte);
  }
  
  // Small delay for stability
  delay(15);
}

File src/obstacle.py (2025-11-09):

# obstacle.py
# Vehicle control for obstacle challenge using camera-based detection and sensor fusion.
# MicroPython code.
# This script controls an autonomous vehicle in an obstacle course.
# It uses a camera for color detection (red, green, magenta obstacles), combined camera with IMU sensor fusion, 
# gyroscope for heading, and encoder for odometry.
# The vehicle navigates a rectangular course, avoids obstacles based on color (red: right avoid, green: left avoid),
# The formed path by avoiding obstacles is the shortest path possible around each obstacle and the vehicle goes as fast as possible without losing control,
# detects magenta for parking, and performs maneuvers using PID for steering.

import pyb
from machine import Pin, UART, SPI, I2C
import math
import sensor

# Initialize camera sensor
sensor.reset()  # Reset camera settings
sensor.set_pixformat(sensor.RGB565)  # Set pixel format to RGB565 for color detection
sensor.set_framesize(sensor.QVGA)  # Set frame size to QVGA (320x240)
sensor.set_vflip(True)  # Vertically flip the image for reverse mounting
sensor.set_hmirror(True)  # Horizontally mirror the image for reverse mounting
sensor.skip_frames(time=500)  # Skip initial frames to stabilize the sensor

# Gyroscope setup (LSM6DSOX) for reading X-axis angular rate
spi = SPI(5, baudrate=1000000, polarity=1, phase=1)  # Initialize SPI bus 5
cs_pin = Pin("PF6", Pin.OUT_PP, Pin.PULL_UP)  # Chip select pin for gyro

def read_gyro():
    # Read low and high bytes from OUTX_L_G and OUTX_H_G registers
    cs_pin.low()
    spi.write(bytearray([0x28 | 0x80]))  # Address for OUTX_L_G with read bit
    low = spi.read(1)[0]
    spi.write(bytearray([0x29 | 0x80]))  # Address for OUTX_H_G with read bit
    high = spi.read(1)[0]
    cs_pin.high()
    raw = (high << 8) | low  # Combine high and low bytes
    if raw >= 32768:
        raw -= 65536  # Convert to signed 16-bit value
    return raw * 0.035  # Scale raw value to degrees per second (adjust scale factor based on sensitivity setting)

# Front ToF sensor setup for obstacle distance
i2c = I2C(2)  # Initialize I2C bus 2
tof_address = 0x29  # Default address for VL53L1X front ToF sensor

def read_distance():
    # Read 2 bytes from register 0x1E (distance result)
    result = i2c.readfrom_mem(tof_address, 0x1E, 2)
    return (result[0] << 8) | result[1]  # Combine to get distance in mm

# Servo setup for steering
SERVO_MIN = 1775  # Minimum pulse width for servo
SERVO_CENTER = 2575  # Center pulse width
SERVO_MAX = 3275  # Maximum pulse width
servo_timer = pyb.Timer(4, freq=50)  # Timer for 50Hz PWM
servo = servo_timer.channel(3, pyb.Timer.PWM, pin=pyb.Pin(2))  # PWM on used pin 2
servo.pulse_width(SERVO_CENTER)  # Initialize to center

def set_steering(pos):
    # Convert position (0-480) to pulse width, clamped to min/max
    pos = max(0, min(480, pos))
    if pos < 240:
        pulse = SERVO_CENTER - (240 - pos) * (SERVO_CENTER - SERVO_MIN) // 240
    else:
        pulse = SERVO_CENTER + (pos - 240) * (SERVO_MAX - SERVO_CENTER) // 240
    servo.pulse_width(int(pulse))

# Motor setup for drive
motor_timer = pyb.Timer(1, freq=20000)  # High freq for smooth PWM
motor_forward = motor_timer.channel(2, pyb.Timer.PWM, pin=Pin(3))  # Forward PWM on pin 3
motor_reverse = motor_timer.channel(3, pyb.Timer.PWM, pin=Pin(6))  # Reverse PWM on pin 6

def set_speed(speed):
    # Set motor speed (-100 to 100), using PWM percent
    speed = max(-100, min(100, int(speed)))
    if speed > 0:
        motor_forward.pulse_width_percent(100)
        motor_reverse.pulse_width_percent(100 - speed)
    elif speed == 0:
        motor_forward.pulse_width_percent(100)
        motor_reverse.pulse_width_percent(100)
    else:
        motor_forward.pulse_width_percent(100 + speed)
        motor_reverse.pulse_width_percent(100)

set_speed(0)  # Start stopped

# UART for communication with slave MCU (sensors: left/right ToF, encoder)
uart = UART(9, baudrate=115200, bits=8, parity=None, stop=1)

tof_left = 0  # Left ToF distance
tof_right = 0  # Right ToF distance
encoder = 0.0  # Encoder value (distance in mm)
uart_buffer = b''  # Buffer for UART data

def fetch_data(command, timeout=50):
    # Send command to slave and parse response
    global tof_left, tof_right, encoder, uart_buffer
    uart.write(command)
    if command in (b'z', b'p'): return True  # No response needed
    start_time = pyb.millis()
    while pyb.elapsed_millis(start_time) < timeout:
        if uart.any():
            uart_buffer += uart.read(uart.any())
            if b'\n' in uart_buffer:
                line, uart_buffer = uart_buffer.split(b'\n', 1)
                if command == b'r' and line.count(b',') == 2:
                    parts = line.split(b',')
                    tof_left = int(parts[0])
                    tof_right = int(parts[1])
                    encoder = float(parts[2])
                    return True
    return False  # Timeout

# Button for start
button_pin = Pin('A0', Pin.IN, Pin.PULL_UP)
def wait_button(release=True):
    # Wait for button press (and release if specified)
    while button_pin.value(): pyb.delay(1)
    if release:
        while not button_pin.value(): pyb.delay(1)

# RGB LED for status
led_pins = [pyb.Pin(p, pyb.Pin.OUT_PP) for p in ("PE3", "PC13", "PF4")]  # R, G, B pins
def set_led(color):
    # Set LED color based on string code (e.g., 'R' red, 'G' green, 'M' magenta, 'off')
    led_pins[0].value(0 if color in 'ROMWY' else 1)  # Red on/low for certain colors
    led_pins[1].value(0 if color in 'GOCWY' and (color != 'O' or pyb.millis() % 1 < 1) else 1)  # Green, with blink for 'O'
    led_pins[2].value(0 if color in 'BCMW' else 1)  # Blue

# Camera parameters
CAM_WIDTH = 316  # Effective width after windowing if applied
CAM_HEIGHT = 115  # Effective height
CAM_CENTER = CAM_WIDTH // 2  # Center for error calculation
TARGET_DIST = 150  # Target distance to obstacles in mm

# Color thresholds in LAB for find_blobs (L_min, L_max, A_min, A_max, B_min, B_max)
th = {
    "R": [(25, 65, 35, 75, -10, 20)],  # Red obstacle
    "G": [(30, 70, -40, -10, 10, 50)],  # Green obstacle
    "OB": [(5,60,5,20,0,25),(5,60,5,80,-80,-25)],  # Orange/Blue (combined or alternative)
    "BK": [(0,25,-10,20,-15,10)],  # Black (not used in obstacles)
    "M": [(40, 80, 60, 90, -20, 30)]  # Magenta for parking
}

def detect_region(color_key, roi=(0, 0, CAM_WIDTH, CAM_HEIGHT)):
    # Use find_blobs to detect regions of the specified color threshold
    # Returns error (deviation from center) and detection flag
    img = sensor.snapshot()  # Capture image
    blobs = img.find_blobs(th[color_key], roi=roi, pixels_threshold=200, area_threshold=200, merge=True)  # Find blobs with params
    if blobs:
        # Take the largest blob for reliability
        largest_blob = max(blobs, key=lambda b: b.pixels())
        center_x = largest_blob.cx()  # Centroid x
        return center_x - CAM_CENTER, True  # Error from center
    return 0, False  # No detection
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

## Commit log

2025-03-25 First commit files upload
    [Pin Header 1x2 TH Pitch 2.54mm.stp, Pin Header 1x8 TH Pitch 2.54mm.stp, Pin Header 1x9 TH Pitch 2.54mm.stp]
2025-05-16 add recent 3d design model files
    [1_adet_design_ackermann_servo_arm.stl, 1_adet_design_spur_25_gear.stl, 1_adet_design_spur_26_gear.stl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]
2025-05-16 upload button_photo.py
2025-11-08 complete models and src files
    [4_gear_design_mini_differential.3mf, design_4_gear_mini_differential.3mf, design_ackermann_servo_arm.stl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]
